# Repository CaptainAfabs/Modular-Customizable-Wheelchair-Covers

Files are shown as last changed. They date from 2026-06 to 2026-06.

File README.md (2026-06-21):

# Modular Customizable Wheelchair Covers

**A patent-pending, open-source spoke guard for manual and power wheelchairs.**
Print it on any consumer 3D printer. Assemble it with zip ties. Customize the colors however you want. It's free, and it will stay free.

Installed cover on a wheelchair drive wheel

---

## The story

This project exists because of my Aunt Laura.

Laura has severe cerebral palsy. She has lived her whole life with involuntary muscle movements that can drive her hand into the spokes of her wheelchair without warning. On one shopping trip, that's exactly what happened — she broke her finger.

We went looking for a fix. The commercial spoke guards we found were either too expensive, looked like clinical equipment, or weren't customizable enough for her to feel like *her*. Laura is a Texas Rangers fan. She likes to decorate for Christmas. None of the off-the-shelf options let her pick a color, let alone a pattern.

So I designed one for her, and then I designed it so anyone could print one for somebody they love.

I filed a US provisional patent with the USPTO on Thanksgiving week 2025 — not to make money, but to make sure **no company can ever patent this design first and then price it out of reach.** This repo is the public release: the CAD files, the drawings, the print settings, the assembly walkthrough, and the patent specification itself. Everything you need to make your own. Forever.

---

## What it is

A modular wheelchair drive-wheel cover that:

- **Prints in 8 pieces per wheel** — each segment spans about 45°, fits a 250 mm print bed, and a full set takes a single overnight print job on most printers.
- **Assembles with zip ties** — no glue, no special tools, no proprietary fasteners. About 30 standard 3 mm × 100 mm ties per wheel.
- **Uses a tongue-and-groove keyed seam** between segments to align panels and resist flex.
- **Fits common manual wheelchair wheels up to ~26"** (61 cm), with or without a hand rim.
- **Is fully customizable** — swap a single segment when it gets scuffed; print sets in team colors, holiday themes, or any pattern you want.
- **Is repairable** — break one panel, reprint one panel. No need to replace the whole cover.

| Installed | Side view | Routing schematic |
|---|---|---|
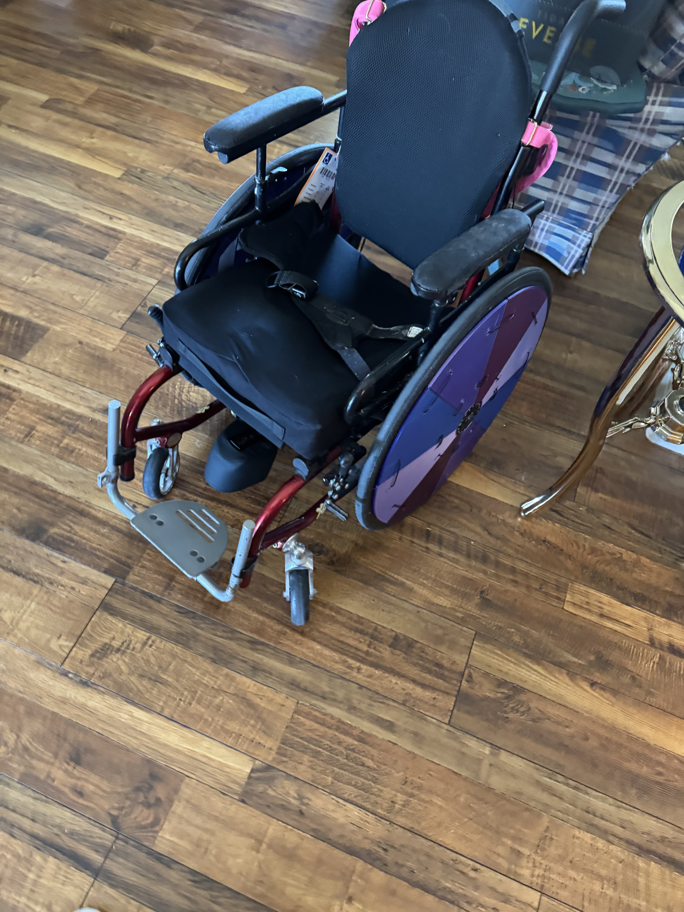
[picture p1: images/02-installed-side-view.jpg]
Side
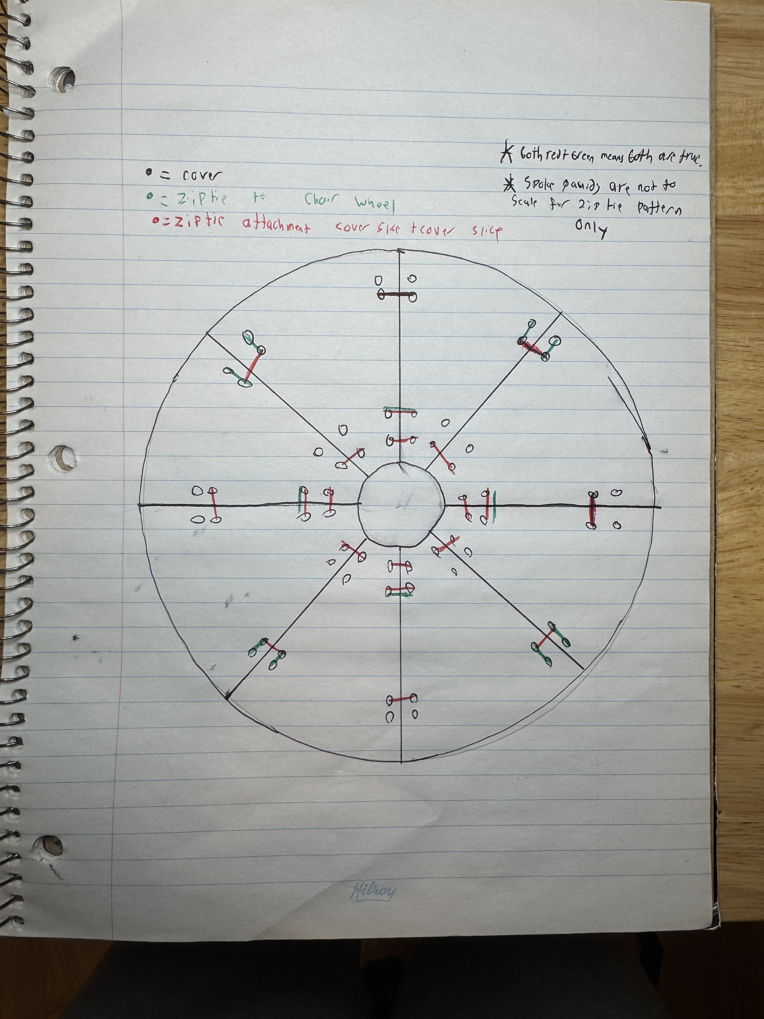
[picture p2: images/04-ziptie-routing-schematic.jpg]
Ziptie schematic
| Hero shot |  |  |

---

## Quick start

1. **Print** — 8 segments per wheel using the [STL](hardware/stl/Wheelchair-Spokeguard-Segment.stl) or open the [Fusion 360 source](hardware/cad/Wheelchair-Spokeguard.f3d) to scale it. See [docs/PRINT_SETTINGS.md](docs/PRINT_SETTINGS.md) for the recipe I use.
2. **Gather hardware** — a bag of cable ties (3 mm × 100 mm, ~30 per wheel) and flush cutters. See [docs/BOM.md](docs/BOM.md).
3. **Assemble** — clip the segments together using the tongue-and-groove seams and the seam apertures. Walkthrough in [docs/ASSEMBLY.md](docs/ASSEMBLY.md).
4. **Install** — zip-tie the assembled disc to the outboard side of the wheel, around the spokes or hand-rim posts. Walkthrough in [docs/INSTALLATION.md](docs/INSTALLATION.md).
5. **Customize** — paint, swap colors per segment, engrave a name. Ideas in [docs/CUSTOMIZATION.md](docs/CUSTOMIZATION.md).

Total cost per wheel, in mid-2026 USD: roughly **$3–6** in filament and **$2–3** in zip ties.

---

## Repo contents

```
.
├── README.md                          You are here
├── LICENSE                            CERN-OHL-S v2 (strong copyleft)
├── PATENTS.md                         Explicit royalty-free patent grant
├── NOTICE                             Attribution
├── CONTRIBUTING.md                    How to help
│
├── hardware/
│   ├── cad/Wheelchair-Spokeguard.f3d              Fusion 360 source (parametric)
│   ├── stl/Wheelchair-Spokeguard-Segment.stl      Ready-to-slice segment
│   └── drawings/
│       ├── Wheelchair-Spokeguard-Segment-Drawing.pdf
│       ├── Spoke-Connector-Drawing.pdf
│       └── Spoke-Cover-Assembly-Drawing.pdf
│
├── docs/
│   ├── ASSEMBLY.md                    Step-by-step segment assembly
│   ├── INSTALLATION.md                Mounting the disc on the wheel
│   ├── PRINT_SETTINGS.md              The print recipe that works for me
│   ├── BOM.md                         Hardware & material shopping list
│   ├── CUSTOMIZATION.md               Patterns, colors, ideas
│   └── patent/
│       ├── Modular-Segmented-Wheel-Cover-Patent-Spec.docx
│       └── Origin-and-Inventor-Statement.docx
│
└── images/
    ├── 01-installed-hero.jpg
    ├── 02-installed-side-view.jpg
    ├── 03-installed-detail.jpg
    ├── 04-ziptie-routing-schematic.jpg
    └── videos/
        ├── demo-1.mov
        └── demo-2.mov
```

---

## Color examples

Same eight-segment design, different palettes. Mix and match per segment to get whatever pattern you want — team colors, holiday themes, alternating stripes, or one-off panels with a name engraved.

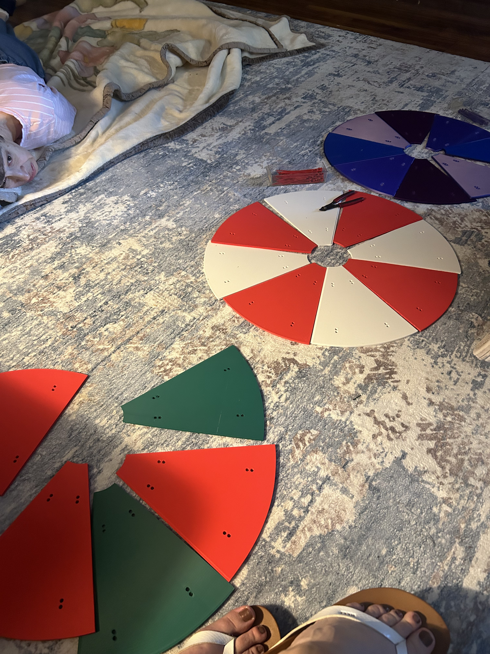
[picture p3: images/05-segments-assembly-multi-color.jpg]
Segments laid out during assembly across red/white, blue/lavender, and green/red sets


Green-and-red set installed on a wheelchair drive wheel

---

## License and the patent

**Code, CAD, drawings, and documentation: [CERN-OHL-S v2](LICENSE)** — the strongly reciprocal open-hardware license. If you modify this design and distribute it (or products made with it), you must release your modifications under the same license. This is deliberate. The whole point of releasing this design is that nobody should ever be able to fence it off again.

**Patent: US provisional filed with the USPTO on November 27, 2025 by Adam Fabiano.** The patent is dedicated to the public under the terms in [PATENTS.md](PATENTS.md). In plain English:

- You can print, build, modify, share, sell, and remix this design royalty-free, as long as you do not weaponize patent rights against anyone else doing the same.
- The patent exists *only* to prevent a third party from patenting the design and locking it down.

If you want to fork this and sell prints to recover your time and filament cost — please do. Just don't try to lock the design away.

---

## Why the patent at all?

A common question: if you want this to be open, why patent it?

Because "open" without a defensive grant is fragile. A few months after a design becomes popular, a company can patent a near-identical version and send takedowns to every maker, Etsy seller, and disability nonprofit producing it. By being the first to file and then granting it to the public, this design is permanently in the commons. The patent is not a fence; it is the proof that there is no fence.

This is the same strategy used by Tesla's Open Patent Pledge and the [Open COVID Pledge](https://opencovidpledge.org), at a much smaller scale.

---

## Contributing

I welcome:

- **Remix forks** with different segment counts, wheel sizes, or seam profiles (please link back).
- **Pattern packs** — STL or texture files for decorated segments.
- **Translations** of the assembly guide.
- **Photos of yours installed** — open a "Show & Tell" issue. I'd love to see them.

See [CONTRIBUTING.md](CONTRIBUTING.md) for details.

---

## Built with Claude

Honest disclosure for anyone curious: I am 18 years old, and I used [Claude](https://claude.ai) for two specific things on this project:

- **Tightening the patent specification.** I drafted the invention; Claude helped me get the legal language into the right structure (Claims, Detailed Description, Best Mode) so the provisional filing was actually usable.
- **Drafting some of the technical-spec text** in this README and in `docs/PRINT_SETTINGS.md`.

Everything physical — the design decision to make it modular, the segment geometry, the tongue-and-groove seam, the zip-tie attachment method, the CAD in Fusion 360, the print testing on my own printer, and the working prototypes mounted on my aunt's chair — is mine. Claude was a writing collaborator, not the engineer.

---

## For Laura

For Laura, whose broken finger became this project. For wanting Texas Rangers colors instead of beige.

— Adam Fabiano, June 2026

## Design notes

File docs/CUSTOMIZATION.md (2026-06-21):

# Customisation ideas

The whole reason the cover is modular is so the user can pick *how it looks*. A wheelchair is not a piece of medical equipment to the person sitting in it — it's the thing they spend their day in. It should reflect them.

Some starting points:

## Per-segment colour

The simplest customisation: print each of the 8 segments in a different colour.

- **Team kits** — alternate two colours around the wheel (my aunt's wheels are Texas Rangers blue + red).
- **Pride flags** — 8 segments fits a lot of flag stripes cleanly. Trans flag (5 colours) and rainbow flag (6 colours) both work as alternating patterns. Bi (3) and pan (3) flags rotate cleanly.
- **Gradient** — print all 8 in shades of a single colour, lightest at the top, darkest at the bottom.
- **Seasonal** — keep a "winter" set (white + silver), a "fall" set (orange + brown), a "Christmas" set (red + green) and swap when the season changes. Each set takes one overnight print.

## Surface treatments

- **Acrylic paint** — Krylon Fusion or Rust-Oleum 2X spray paint bonds to PETG and ABS without primer.
- **Paint pens** — for fine line work, geometric patterns, mandalas, names.
- **Vinyl decals** — cricut cut a number, logo, or shape; press onto a printed segment after a quick alcohol wipe.
- **Permanent markers** — Sharpie Industrial holds up outdoors better than regular Sharpie.
- **Multicolour print** — if you have AMS / MMU / a Palette, the segment top face takes 2-colour designs well.

## Print-in patterns

Modify the F3D file (or your STL slicer) to:

- **Engrave a name or number** into one segment.
- **Cut a logo or shape clear through** a segment for a stained-glass effect when the wheel turns.
- **Texture the surface** — a knurled or honeycomb top face changes the look and the way light hits.
- **Add raised lettering** — slogans, team mottos, birthday messages.

## Themed sets I've thought about

- **Birthday wheel** — print a one-day set in someone's favourite colours; cut their age out of one segment.
- **Wedding wheel** — for a wheelchair-using person at their own or someone else's wedding, white + their accent colour. Doesn't need to be reverent.
- **Halloween** — alternate black and orange; engrave bats or pumpkins.
- **Memorial** — a quiet single-colour set in someone's honour, with a name or date on one segment.

## Sharing

If you make a set worth showing off, open an issue with the **"Show & Tell"** label and share photos. I'd love a folder of community customisations in this repo eventually.

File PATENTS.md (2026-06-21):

# Patent Grant

## Plain-English summary

A US provisional patent application titled **"Modular Segmented Wheel Cover for a Wheelchair Drive Wheel and Methods of Making and Installing the Same"** was filed with the **United States Patent and Trademark Office (USPTO) on November 27, 2025** by Adam Fabiano. The provisional spec is included verbatim in [`docs/patent/`](docs/patent/).

**The patent exists for one reason: to keep this design in the public commons.**

I, Adam Fabiano, irrevocably grant every person and organisation a worldwide, royalty-free, perpetual, non-exclusive licence to **make, have made, use, sell, offer for sale, import, and distribute** anything covered by this patent (and any patent that issues from it, in any jurisdiction), including derivative works, **for any purpose**, subject only to the conditions in the next section.

You do not need to ask permission. You do not need to pay anyone. You do not need to attribute me, though I'd love it if you did.

## Conditions on the patent grant

This patent grant is **defensive** in the sense of the [Apache 2.0 §3 patent termination clause](https://www.apache.org/licenses/LICENSE-2.0#patent) and the [Open Invention Network](https://openinventionnetwork.com/) model:

1. **You lose this patent licence** if you initiate patent litigation (including a cross-claim or counterclaim in a lawsuit) alleging that this design, or any product implementing it, infringes a patent of yours. In that case, your rights under this grant terminate as of the date the litigation is filed.
2. **You lose this patent licence** if you attempt to patent this design — or a substantially similar design — anywhere in the world after the date of this grant. (You're free to patent your own genuine improvements; you're not free to re-fence the underlying idea.)
3. The grant is non-sublicensable in the sense that you can't grant *narrower* rights than you received. Anyone who receives a copy of the design gets the same patent licence directly from me.

These conditions exist solely to stop the design from being captured by a patent troll or by a company trying to monopolise a low-cost accessibility device. If you are a maker, a clinic, a charity, a hobbyist, a small business, a 3D-printing service, or a large manufacturer producing these for users — **you have every right you need.**

## Combined effect with the LICENSE

The copyright on the CAD files, drawings, documentation, and source content in this repository is licensed under [CERN-OHL-S v2](LICENSE). The patent grant in this file is **separate from but compatible with** the CERN-OHL-S v2 patent provisions (§3.5 of that licence). Where the two overlap, the broader of the two grants applies in favour of the user.

## Jurisdictions

The provisional application was filed with the USPTO in the United States. The intent of this grant is worldwide. If a corresponding patent issues in any other jurisdiction (Canada, EU, PCT national phase, etc.) — including via a non-provisional or PCT application claiming priority to this provisional — it is automatically subject to the same grant the moment it issues, with no further action required by me.

## Why this exists

A few months after a design becomes popular online, a company can patent a near-identical version and start sending takedowns to makers, Etsy sellers, and disability nonprofits. By being the first to file *and* by granting the result to the public on these terms, this design is permanently in the commons and cannot be fenced off again.

The patent is not a fence. It is the proof that there is no fence.

— Adam Fabiano
Provisional filed November 27, 2025 (USPTO). Repository published June 2026.

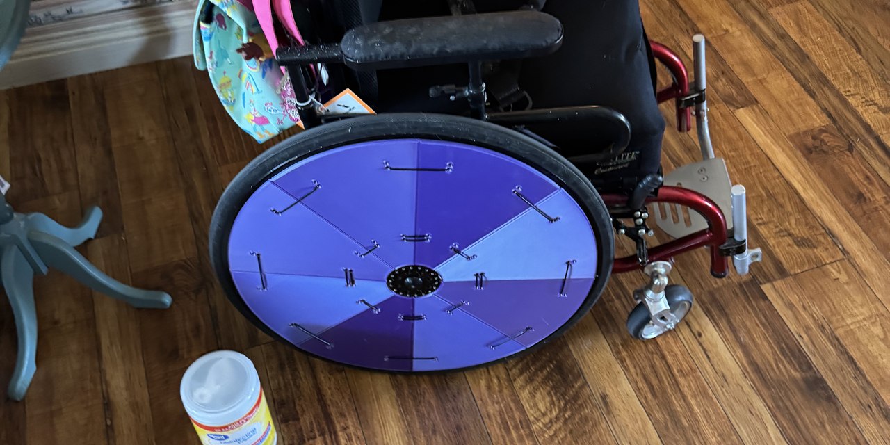
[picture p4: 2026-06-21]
images/social-preview.jpg

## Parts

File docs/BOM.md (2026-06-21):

# Bill of materials

Everything you need to make one full set (both wheels covered).

## Printed parts

| Part | Qty | Source |
|---|---|---|
| Spokeguard segment | 16 (8 per wheel) | [hardware/stl/Wheelchair-Spokeguard-Segment.stl](../hardware/stl/Wheelchair-Spokeguard-Segment.stl) |

Material: ~1 kg of PETG, ABS, ASA, or equivalent. See [PRINT_SETTINGS.md](PRINT_SETTINGS.md).

## Hardware

| Item | Qty per wheel | Qty for both | Spec | Approx cost (mid-2026 USD) |
|---|---|---|---|---|
| Cable ties (zip ties) | ~30 | ~60 | **3 mm wide × 100 mm long**, nylon, black or any colour | $3–5 for a bag of 100 |
| Cable ties — spare | 10 | 20 | Same spec | included above |

Acceptable substitutes (the design works with any of these, with minor changes to routing):

- 2.5 mm × 100 mm ties — works fine, slightly easier to thread, holds about as well.
- 4.8 mm × 200 mm ties — works only on the wheel-attachment holes, not the seam apertures.
- Reusable silicone ties or hook-and-loop straps — for users who need to remove the cover often (e.g., before a flight).
- Wire ties / metal cable ties — for high-heat outdoor use.

## Tools

| Tool | Required? | Why |
|---|---|---|
| Flush cutters or sharp side cutters | **Required** | To trim tie tails close to the head so they don't snag clothing. |
| Pliers (standard) | Optional | Helps pull ties tight when you have a lot of friction. |
| Deburring tool or hobby knife | Optional | Clean up any stringing around aperture edges. |
| 4 mm drill bit (hand-twist) | Optional | Clear any aperture that printed slightly closed. |
| Sandpaper (200/400 grit) | Optional | Tune the tongue-and-groove fit if your printer runs tight. |
| Sharpie or paint pens | For customising | Add names, patterns, jersey numbers. |

## Optional: customisation supplies

- Acrylic spray paint (Krylon Fusion or Rust-Oleum 2X work well on PETG and ABS).
- Vinyl decals or stickers.
- Permanent markers (Sharpie Industrial holds up better outdoors than regular Sharpie).
- Acrylic paint pens for fine line work.

See [CUSTOMIZATION.md](CUSTOMIZATION.md) for ideas.

## Total cost estimate

| | One wheel | Both wheels |
|---|---|---|
| Filament | ~$2.50 | ~$5 |
| Zip ties | ~$2 | ~$3 |
| **Total** | **~$5** | **~$8** |

Tools are reusable across many projects and not counted in the per-wheel cost.

For comparison, the cheapest commercially-available customisable spoke guards we found in early 2026 ran **$80–150 per pair**.

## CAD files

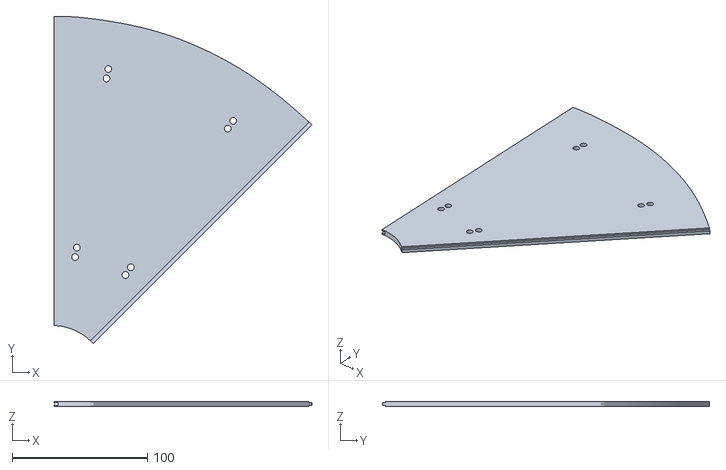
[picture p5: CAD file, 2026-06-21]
hardware/stl/Wheelchair-Spokeguard-Segment.stl
190.7 x 241.9 x 4.00

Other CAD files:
hardware/cad/Wheelchair-Spokeguard.f3d

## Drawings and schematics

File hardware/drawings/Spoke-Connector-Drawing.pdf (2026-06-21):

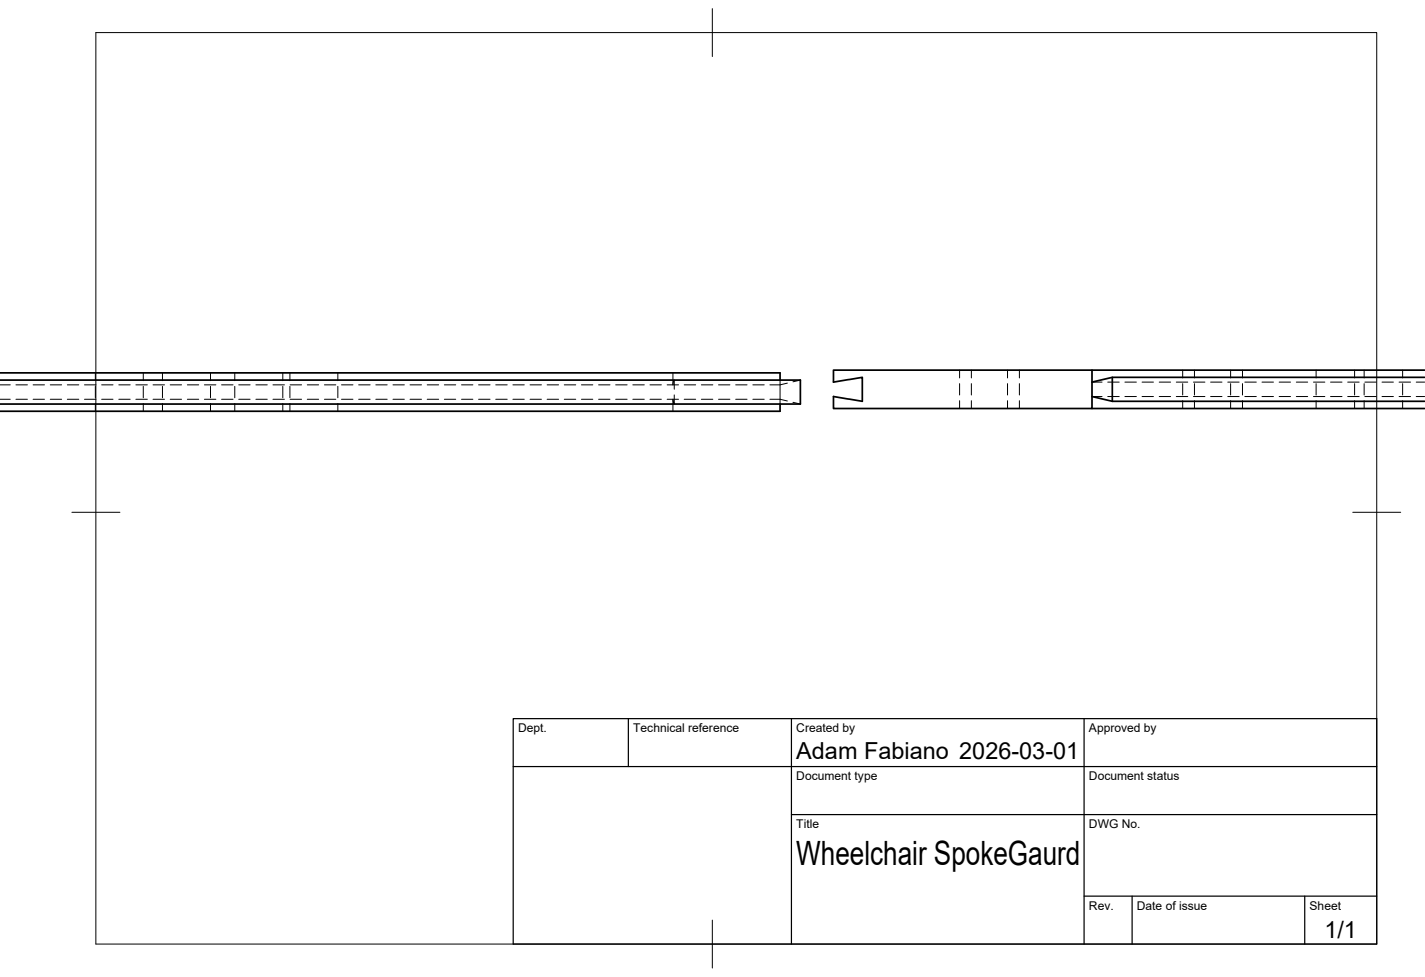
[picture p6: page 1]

Dept. | Technical reference | Created by Adam Fabiano 2026-03-01 | Approved by

Document type | Document status

Title Wheelchair SpokeGaurd | DWG No.

Rev. | Date of issue | Sheet 1/1

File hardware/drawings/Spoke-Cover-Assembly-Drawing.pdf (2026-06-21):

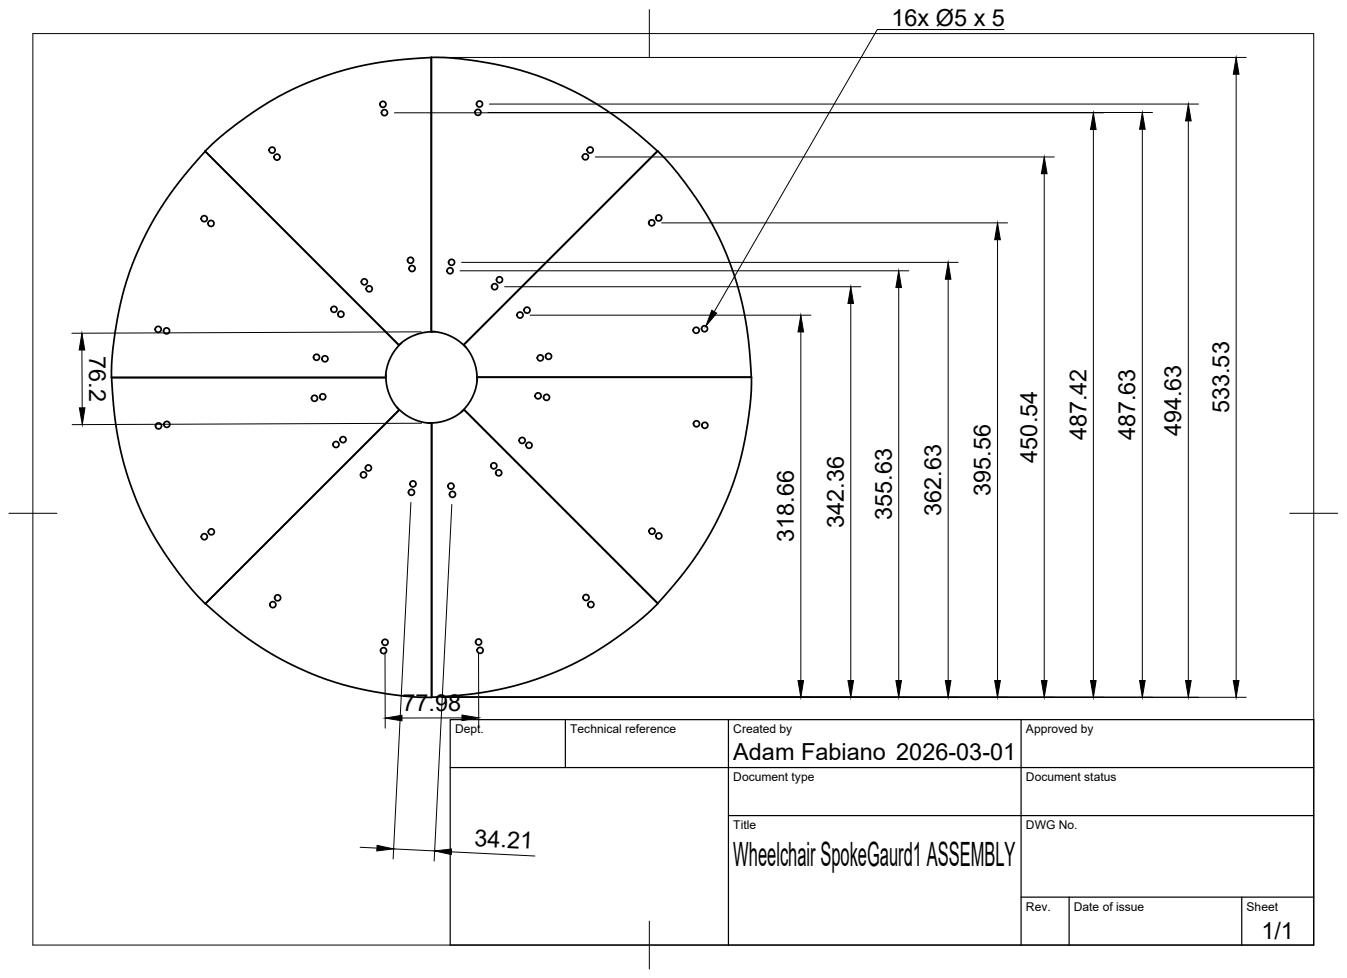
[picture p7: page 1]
Dept.; Technical reference; Created by; Approved by; Adam Fabiano

Document type | Document status

Title Wheelchair SpokeGaurd1 ASSEMBLY | DWG No.

Rev. | Date of issue | Sheet 1/1

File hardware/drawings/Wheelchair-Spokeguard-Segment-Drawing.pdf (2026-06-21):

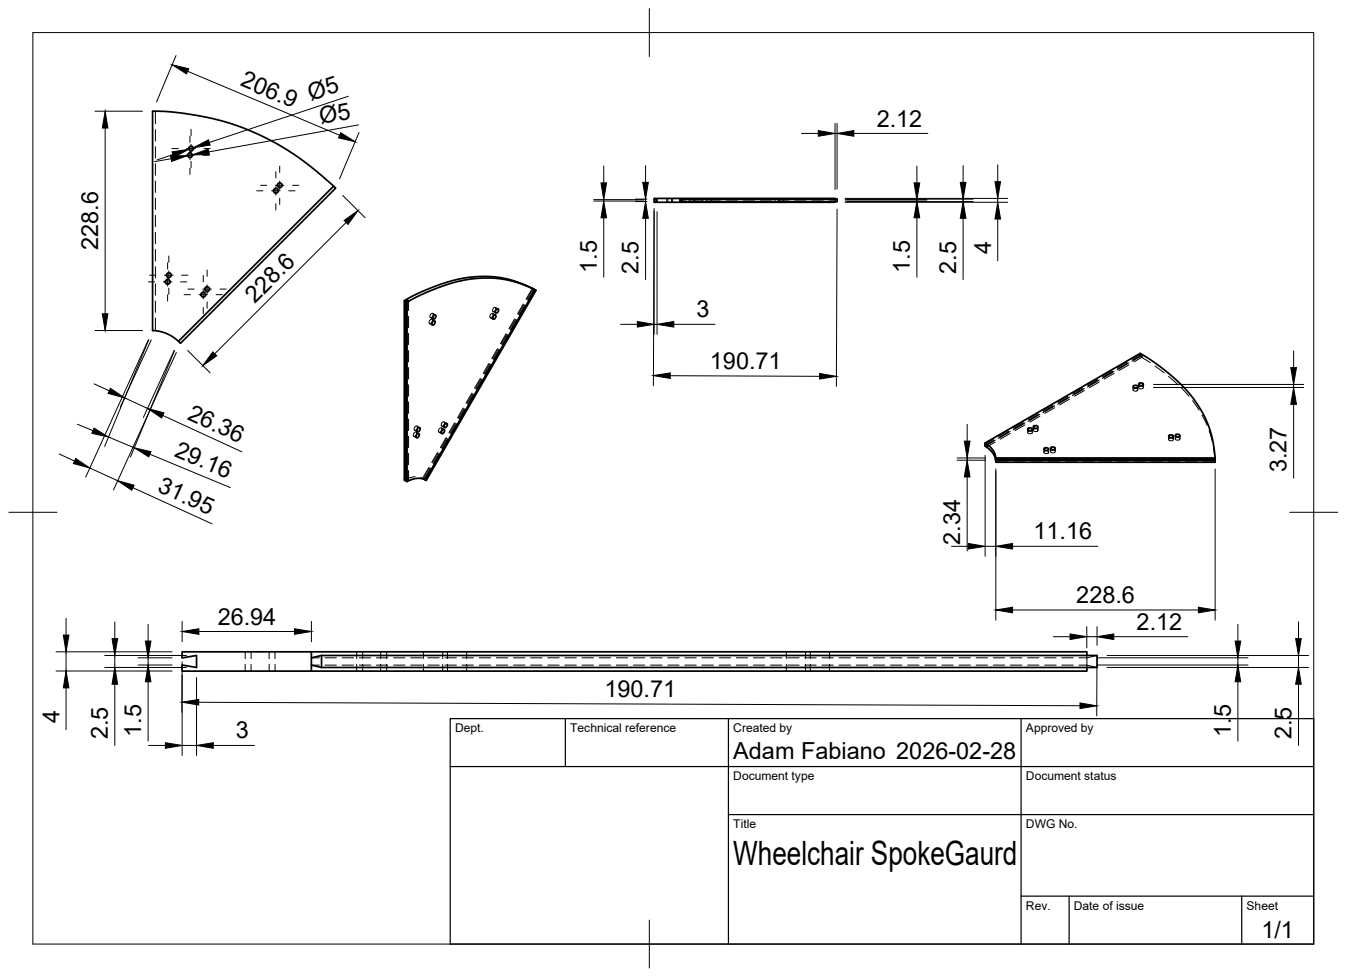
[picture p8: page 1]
Dept.; Technical reference; Created by; Approved by

Adam Fabiano 2026-02-28

Document type | Document status

Title Wheelchair SpokeGaurd | DWG No.

Rev. | Date of issue | Sheet 1/1

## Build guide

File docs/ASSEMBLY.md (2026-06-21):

# Assembling a disc

This guide covers joining 8 printed segments into a single rigid disc, **before** you mount it on the wheel. Mounting is covered in [INSTALLATION.md](INSTALLATION.md).

**Time:** About 15 minutes per disc once you've done it once.

**You need:**
- 8 printed segments (per disc)
- ~16 zip ties (3 mm × 100 mm) — two per seam
- Flush cutters

---

## Step 1 — Lay out the segments

Lay the 8 segments **face down on a flat surface** in a rough circle, with the tongue edge of each segment pointing the same way (e.g., clockwise). Each segment has:

- An **arcuate outer edge** (the curved side that will form the rim of the disc).
- An **inner edge** (a short straight piece that, with the other 7 segments, forms the central aperture for the hub).
- A **tongue edge** on one radial side and a **groove edge** on the other.
- Multiple **apertures** (round holes) and **slots** along the edges for zip ties.

> **Why face down?** When you flip the assembled disc onto the wheel, the side that was facing you during assembly becomes the **inboard** side (the side facing the spokes). All zip-tie heads should end up on the inboard side so the outboard face stays clean.

## Step 2 — Engage the first seam

Pick two adjacent segments. Slide the **tongue** of one into the **groove** of the other so the radial edges meet flush. You should feel a positive click or slight friction; the tongue is intentionally slightly undersized to allow for printer tolerance.

If the tongue is too tight: sand it gently along its length with 200-grit sandpaper.
If it's too loose: you can still secure the seam with ties; the fit will tighten as you add more segments.

## Step 3 — Tie the seam

Each seam uses **two zip ties** — one closer to the centre, one closer to the rim.

1. Thread a zip tie through the matching aperture pair that **bridges the seam** (one hole in each segment). The tie should enter from the side facing you (which will be inboard) and exit on the same side.
2. Loop the tie back around the bridge between the two holes and feed the tail into the head.
3. Pull tight by hand. Don't over-tighten — you want the seam snug, not crushed.
4. Repeat for the second tie at a different radius.

> **Why two ties per seam?** A single tie can pivot around itself; two ties at different radii prevent the seam from rotating under hand impact.

## Step 4 — Repeat around the disc

Add segments one at a time. Each new segment engages the tongue of the previous one and provides a groove for the next. After segment 8 you'll close the loop by tying segment 8 back to segment 1.

> **Tip:** When closing the last seam, you may need to flex two segments apart slightly to get the tongue into the groove. The seam fasteners on either side will hold the deflection elastically; this is normal.

## Step 5 — Check the disc

Lift the assembled disc by the rim. It should:

- Feel rigid in the plane of the disc (no flex side-to-side).
- Have an even circular outer edge with no visible step at any seam.
- Have a clean central aperture roughly centred on the disc.
- Have **all 16 zip-tie heads on the same side** (the side that will become inboard).

If a seam shows a step or gap, loosen its two ties, re-seat the tongue, and re-tighten.

## Step 6 — Trim the tails

Use **flush cutters** to snip every zip-tie tail as close to the head as possible. Run a finger over each one — there should be **no sharp edge**. If you feel a burr, trim again.

> **Why flush trim matters:** The tails sit on the inboard side, close to the user's lap and clothing. A snagged tail can tear pants or scratch skin. Flush cutters and a careful touch are the difference between a comfortable cover and a hazardous one.

## You're done

You now have one assembled disc. Repeat for the second wheel before moving on to [INSTALLATION.md](INSTALLATION.md).

---

## Routing diagram (reference)

The hand-drawn schematic below shows the zip-tie routing pattern I worked out for my aunt's chair. **Red ties** are seam fasteners (the ones in this assembly step); **green ties** are wheel-attachment fasteners (covered in [INSTALLATION.md](INSTALLATION.md)).

Ziptie routing schematic

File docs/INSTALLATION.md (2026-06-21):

# Installing the disc on a wheelchair

This guide assumes you have **one assembled disc per wheel** ready to go. If you don't, do [ASSEMBLY.md](ASSEMBLY.md) first.

**Time:** About 10–15 minutes per wheel, once.

**You need:**
- 1 assembled disc per wheel
- ~14 zip ties (3 mm × 100 mm) per wheel — these are the wheel-attachment fasteners
- Flush cutters
- A way to immobilise the wheel (lock the brake, or have a helper)

---

## Before you start

1. **Wipe the spokes and rim clean.** A microfibre cloth is enough.
2. **Find the valve stem of the tire.** It will be your reference point for centring the disc.
3. **Decide which side is outboard** — the side the user faces when looking at the wheel. That's the side the disc goes on.

## Step 1 — Orient the disc

Hold the disc against the outboard side of the wheel with the **zip-tie heads from the assembly step facing the wheel** (inboard). The clean face should be facing you.

The disc has a central aperture that should clear the hub. If it doesn't, either the wheel hub is unusually large or the print was scaled wrong; check fit before you commit to ties.

Rotate the disc so that **each segment lines up with a sensible group of spokes** — there is no required orientation, but matching segment boundaries to spoke directions makes routing easier and looks more deliberate.

## Step 2 — First three anchor ties

Pick three apertures spaced roughly **120° apart** around the disc. For each:

1. Push a zip tie from the outboard face, through the aperture, **around a spoke** (or around a hand-rim post if you have one), and back out through an adjacent aperture in the same segment.
2. Feed the tail into the head from the inboard side.
3. Pull hand-tight — but **don't lock it down yet**. You want adjustability.

After three anchor ties, the disc should be loosely held against the wheel and approximately centred.

## Step 3 — Centre the disc

Spin the wheel slowly by hand. The outer rim of the disc should appear circular — no wobble, no offset toward one side. If it doesn't:

- Loosen one anchor tie.
- Shift the disc by a few millimetres in the needed direction.
- Re-tighten by hand.

Repeat until the disc is centred on the hub when the wheel spins. Aim for **±2 mm** of runout at the outer edge.

## Step 4 — Remaining attachment ties

With the disc centred, add the remaining wheel-attachment ties. A good pattern is **one tie per segment**, distributed around the disc, each routed around a different spoke. Some segments may benefit from two ties (12 o'clock, 3, 6, 9 positions) for extra rigidity.

> **The "double-duty" trick:** Some apertures sit right on a seam between two segments. If you route a tie through one of those, it both (a) joins the seam and (b) attaches the disc to a spoke. One tie, two jobs. This is described in the patent specification.

For each tie:
1. Outboard → through aperture → around spoke → through adjacent aperture → tail to inboard.
2. **Heads on the inboard side**, always.
3. Pull firm but not crushing.

Aim for **about 14 attachment ties per wheel** total, including the three anchor ties from Step 2.

## Step 5 — Final tighten

Once all ties are placed, go around the disc a second time and pull each tie one more notch. The whole assembly should now be rigid against the wheel with no audible rattle when you tap the rim of the disc.

Spin the wheel. The disc should rotate true with the wheel; you should hear nothing rubbing.

## Step 6 — Trim every tail

Use flush cutters to snip every wheel-attachment tail close to the head. **Run a finger over every cut**. No sharp edges anywhere — these will be near the user's hands and lap.

## Step 7 — Hand-rim and brake check

If the chair has a hand rim, **verify the user can still grip it cleanly** — the disc should sit inside the hand-rim posts and not interfere with normal propulsion.

Engage and release the wheel brake. Confirm nothing rubs.

If the chair has a powered drive (like the chair shown in this repo's hero photo), confirm the motor and battery housing are clear.

## Done

Repeat for the second wheel and you're finished. The discs can stay on permanently, or be removed (cut the ties, re-tie next time) for cleaning or travel.

---

## When to inspect

- **Weekly for the first month** — check that no tie has loosened, no segment has cracked.
- **Monthly thereafter** — quick visual check; tighten or replace any compromised tie.
- **After any impact** — if a tie was snagged or a segment was struck hard, replace before next use.

## When to replace a segment

If a single segment cracks or chips badly, you can **swap that segment alone**:

1. Cut the two seam ties on either side of the damaged segment.
2. Cut any attachment ties going through it.
3. Slide it out (the rest of the disc holds together).
4. Slide the replacement in.
5. Re-tie. Trim.

You do not need to dismount the rest of the disc. This is the entire point of modularity.

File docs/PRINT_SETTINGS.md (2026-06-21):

# Print settings

These are the settings I use on my own printer for my aunt's chair. They are tuned for **strength against impact and finger force**, not for speed. If you want to deviate, the only setting I'd strongly warn against changing is the wall count.

## Filament

| Use case | Recommended | Notes |
|---|---|---|
| Indoor / cool-weather outdoor (< ~60 °C) | **PETG** | First choice. Tough, UV-stable enough for daily outdoor use, doesn't shatter. |
| Hot weather, in-car storage, hot climates (< ~95 °C) | **ABS** or **ASA** | Higher heat tolerance. ASA is more UV-stable than ABS. |
| Maximum toughness (rough usage) | **PA (nylon)** or **PC** | Overkill for most users; expensive; harder to print. |
| Budget / first prototype only | PLA | **Not recommended for long-term use.** It will creep in heat and can shatter on hand impact. Use only to verify fit. |

A spool of 1 kg PETG (~$20 USD in mid-2026) is enough for **two full wheels plus spares**.

## Slicer settings

Best results in Bambu Studio, OrcaSlicer, PrusaSlicer, or Cura with the following:

| Setting | Value | Why |
|---|---|---|
| Nozzle | **0.4 mm** (hardened steel preferred) | Standard; hardened resists abrasion if you ever print with glass-filled filament. |
| Layer height | **0.20 mm** | Speed/strength sweet spot. 0.16 mm is fine if you have time. |
| Walls / perimeters | **6** | **Do not reduce this.** Walls do almost all the impact resistance for this part. |
| Top / bottom layers | 4 / 4 | Smooth surface, good visual finish for paint. |
| Infill | **5 % gyroid** | The walls are doing the structural work; infill is just there to prevent the top from sagging. |
| Wall line width | 0.4 mm (default) per loop | Matches nozzle exactly so loops bond cleanly. |
| Z seam | Random or Aligned-back | Random hides better on coloured prints. |
| Ironing | On (top layer only) | Optional, but gives a smoother finish for paint or decals. |
| Supports | Tree, ~30° overhang threshold | Only required around the zip-tie apertures on some slicers. |
| Build plate | PEI or textured powder-coated | No brim, no raft. |
| Brim / raft | None | Part has plenty of bed contact. |
| Nozzle / bed temp | Per filament spec | PETG: ~240 °C / 80 °C. ABS: ~250 °C / 100 °C, enclosure recommended. |

## Print orientation

Print the segment **flat on the bed** (top face up, large face down). This gives:
- Strongest layer adhesion in the direction the cover takes finger impact.
- Cleanest aesthetic top surface for paint or vinyl wrap.
- No supports needed for the seam features.

## How many to print

| You need | Segments to print |
|---|---|
| One wheel covered | 8 |
| Both wheels covered (typical) | 16 |
| A full set with one spare | 17 |
| A full set with one spare per wheel | 18 |

## Print time

On a Bambu P1S / X1C at default PETG profile with these settings, one segment is **about 1 hour 20 minutes**. A full 8-segment wheel set is **roughly 10–11 hours** — comfortably an overnight print.

You can fit **2 segments per build plate** on a 256 mm × 256 mm bed, 3 on some larger printers. Don't try to nest more than that; the segments don't pack efficiently because of the radial geometry.

## Print quality check

Before assembly, look at each segment for:

1. **Clean tongue and groove edges.** No stringing, no elephant-foot blob on the bottom. The tongue should slide into the groove on an adjacent segment with light pressure; if it doesn't fit, sand it lightly along the layer lines.
2. **No clogged apertures.** Every zip-tie hole should be open all the way through. Punch out any film with a 4 mm drill bit or the tip of a flush cutter.
3. **No delamination.** Flex the segment with both hands. If layers separate, your bed temperature was too low or the filament is wet — dry it and reprint.

## Wheel diameter compatibility

The provided STL is sized for the most common manual wheelchair drive wheel (**24 inch / 610 mm**). If your aunt/parent/friend uses a different wheel size:

- **22" or 25"** — use the F3D source file and scale the assembly uniformly. The aperture pattern will still line up with most spoke configurations.
- **20" sport / kids' chair** — scale to 0.85×; check the central aperture clears the hub.
- **26"** — scale to 1.08×; verify your printer can still fit the larger segment.

If you don't have Fusion 360, **the free [Fusion 360 Personal Use license](https://www.autodesk.com/products/fusion-360/personal)** is sufficient to open and modify the source file.

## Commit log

2026-06-21 Initial release: Modular Customizable Wheelchair Covers
    Open-source, USPTO-provisional-patent-protected modular spoke guards
    for manual and power wheelchairs. Print on consumer 3D printers,
    assemble with zip ties, customise the colours.
    Released under CERN-OHL-S v2. The provisional patent (USPTO, filed
    2025-11-27) is dedicated to the public under the terms in PATENTS.md.
    For Laura.
    [Wheelchair-Spokeguard-Segment.stl, Wheelchair-Spokeguard.f3d]
2026-06-21 Add color-example photos: multi-color assembly and green/red install
    - images/05-segments-assembly-multi-color.jpg: red/white, blue/lavender,
    and green/red segment sets laid out mid-assembly
    - images/06-installed-green-red.jpg: green/red eight-segment cover
    installed on a wheelchair drive wheel
    README: new "Color examples" section between repo contents and license,
    showing the design's customizability with real builds.
